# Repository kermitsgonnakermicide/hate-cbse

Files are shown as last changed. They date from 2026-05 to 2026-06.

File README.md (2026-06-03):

# hate-cbse
A desk-sized CoreXY pen plotter with a custom RP2350 based motherboard!

# why? 
### just why?
- i come from the great country of India, and as a result of that I'm in CBSE [(Central Board of Secondary Education)](https://www.cbse.gov.in/)
- CBSE, being a central board(for the entire country) and in general being decades behind other boards/methods has some quirky little requirements which seem utterly useless to the average individual
- one of those requirements is to a 'practical file' for maths, physics, chemistry and biology - these files are supposed to detail every single experiment you do in the lab and their results
- while this has great intentions, it has become so bad that a 'lab manual' has been published and students are expected to copy it word for word(not even kidding there) including the results and submit it
- i went through this myself and now that i'm moving into 11th(junior year) and the volume of experiments shoots straight up, I need a solution to this horrid problem

for additional context, please view this [youtube video](https://www.youtube.com/watch?v=U_G3jSLx4hc)
## enter, the hatecbse plotter
- this is an awesome corexy plotter that has about 300x300 mm of usable space, good enough for all my sheets and stuff
- its frame is built with 20x20 aluminium extrusion and is powered by NEMA17 stepper motors 
- while I initially thought I would skip on making a full on PCB for this project, you only hackclub once so I decided to make my own, printer motherboard-esque concotion around an RP2350B and the TMC2209 steppers(sticking with the breakout boards for that one purely because of cost)
- firmware wise, i'm not smart enough to write CNC plotter firmware so I'm using grblHAL, an opensource piece of firmware for all kinds of CNC plotters - you can check out Firmware/ for my config and and firmware file

# setup guide
- print and assemble the PCB(personally, i'm skipping all THT components for JLC assembly including a couple caps and resistors because I have them at home and they're for imp stuff(would appreciate being able to swap them out))
- print all files in production/Prints (quantity is indicated in the filename)
- assemble the frame(you will need a lot of T nuts for the alumnium extrusions)
- mount the PCB backplate, the motor holders + motor, belt guide
- assemble the toolhead and its profile, along with its linear actuator
- route your timing belts through center, motor pulley and ends
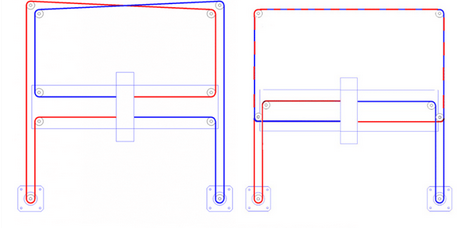
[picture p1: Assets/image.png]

> use this image for reference!
- put PCB on backplate, wire servos, steppers and limit switches to the board and anything else you want to add(I exposed a lot of power and I2C pins)
- give it USB power and 12v 5A power from your favourite power source(personally using my benchtop powersupply, but you could use anything)
- flash firmware and get to plotting!

# note for reviewer(s)
this project will be partially self funded out of sheer necessity, so please do not be concerned about any excess BOM cost

# Images
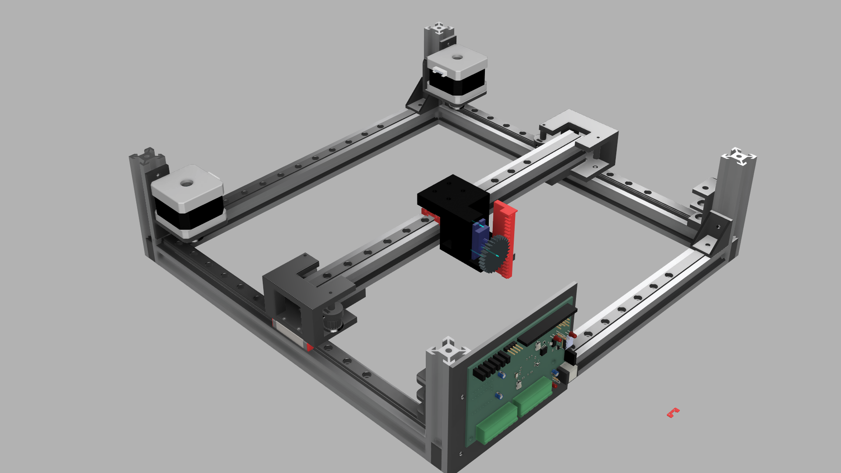
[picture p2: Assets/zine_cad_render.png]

> full render

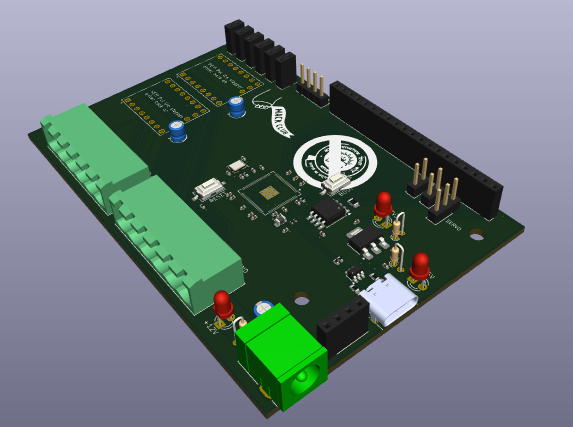
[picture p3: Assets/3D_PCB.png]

>PCB render

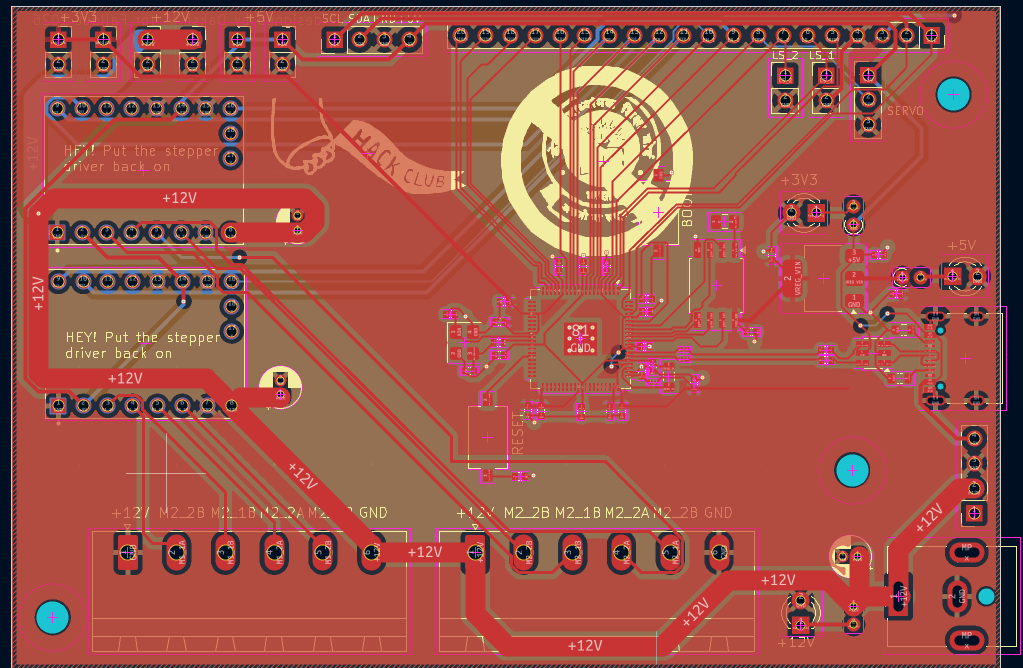
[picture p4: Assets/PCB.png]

> routed PCB

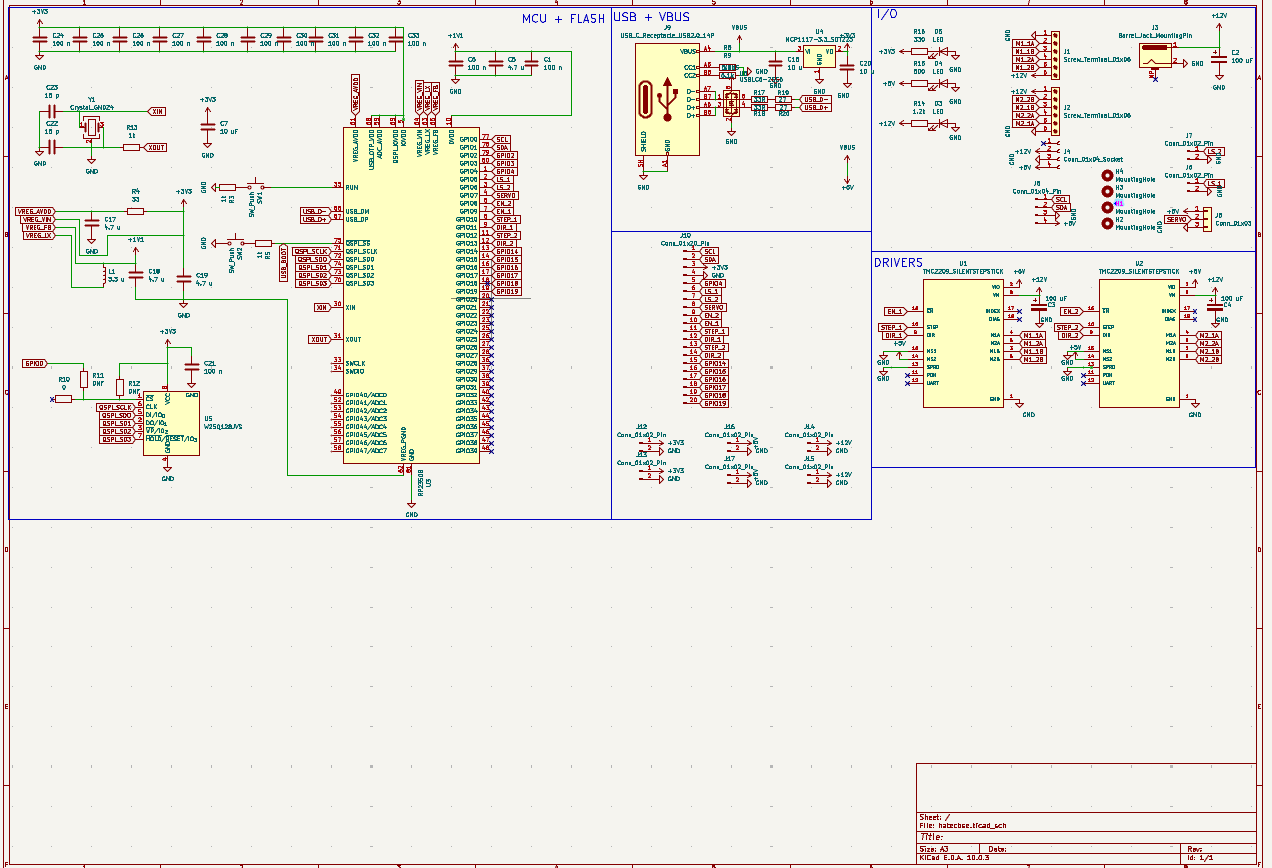
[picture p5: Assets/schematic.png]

> cleaned up schematic

# Zine
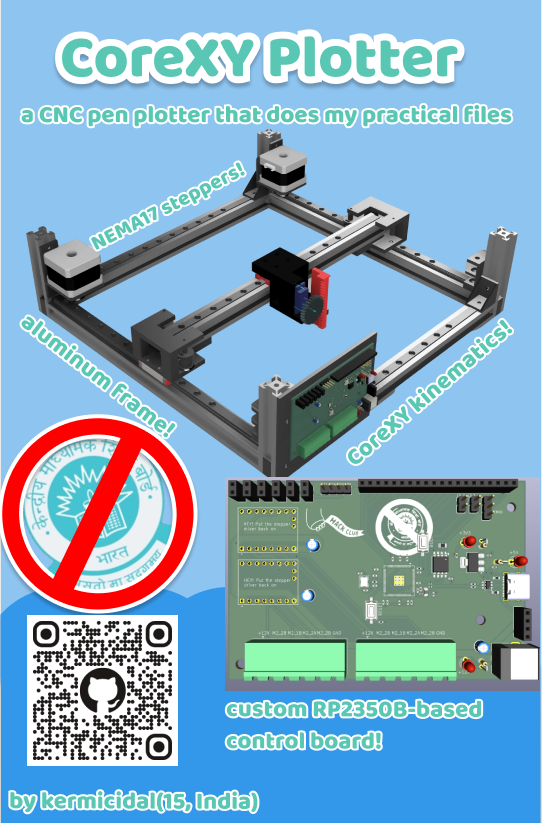
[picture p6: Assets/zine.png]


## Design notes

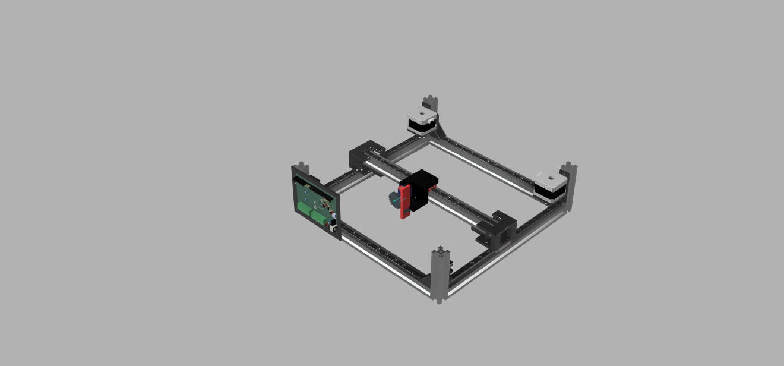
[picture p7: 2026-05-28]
Assets/render_cad.png

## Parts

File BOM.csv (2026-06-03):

Name | Link | Unit Price | Quantity | Total | Running | Notes
MGN9H LInear Rails | https://novo3d.in/mgn9h-linear-rail/?attribute_length=30cm | 10.43 | 3 | 31.29 | 31.29
MGN9H Blocks | https://novo3d.in/linear-guide-rail/?attribute_type=MGN9H | 5.73 | 3 | 17.19 | 48.48
Aluminium 3 way connector | https://novo3d.in/3-way-corner-connector/?attribute_type=2020 | 1.03 | 3 | 3.09 | 51.57
GT2 Timing belt | https://novo3d.in/gt2-timing-belt/ | 0.65 | 1 | 0.65 | 52.22 | Unit Price - 1 meter
2020 Aluminium Profile | https://novo3d.in/aluminium-profiles-2020/ | 6.2 | 1.86 | 11.532 | 63.752 | Unit Price - 1 meter
NEMA 17 | https://novo3d.in/42-stepper-motor/ | 6.05 | 2 | 12.1 | 75.852
TMC2209 | https://novo3d.in/mks-tmc2209/ | 4.54 | 2 | 9.08 | 84.932
MG90 servo | N/A | 0 | 0 | 0 | 84.932 | Already have
GT2 pulley | https://novo3d.in/gt2-pulley-16t-5mm-bore/ | 0.62 | 10 | 6.2 | 91.132
Filament |  | 0 | 0 | 0 | 91.132 | Already have
T nuts | https://novo3d.in/spring-t-nut/?attribute_size=M5 | 0.094 | 20 | 1.88 | 93.012
M5 Bolts | https://robokits.co.in/robot-parts/nut-bolts-standoffs/allen-cap-socket-head-bolts/m5-x-8mm-socket-head-cap-stainless-steel-304-bolt-moq-15pcs | 2.19 | 1 | 2.19 | 95.202 | pack of 15
PCB | please view seperate PCB bom for details |  |  | 92 | 187.202
TOTAL |  |  |  |  | 187.202

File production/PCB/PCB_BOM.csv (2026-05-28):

JLCPCB BOM Tool - BOM Matching
BOM name：bom-JLCPCB Assembly Order.xlsx |  |  | Download Time：2026-05-28 21:02:38 |  |  | * Our matching results are updated in real-time, but stock and prices may change. If it's been over 24 hours, please re-match before placing your order.
PCB Assembled Qty：5 |  |  | Est. Total Price：19.6919
Your BOM |  |  |  |  |  |  |  |  |  |  | Order Information
Top Designator | Bottom Designator | Comment | Footprint | JLCPCB Part # | Part # | Manufacturer | Footprint | Description | Category | Warning | JLCPCB Part # | Product link | Lib Type | Qty | Source | Total Price ($)
C1,C21,C24,C25,C26,C27,C28,C29,C30,C31,C32,C33,C6 |  | 100n | 402 |  | CC0402KRX7R7BB104 | YAGEO | 0402 | 100nF 16V X7R ±10% 0402 Multilayer Ceramic Capacitors MLCC - SMD/SMT ROHS | Multilayer Ceramic Capacitors MLCC - SMD/SMT | 1.The comment (CC0402KRX7R7BB104) of this part does not match the one (100n) provided in your BOM. Please confirm; | C60474 | https://jlcpcb.com/partdetail/YAGEO-CC0402KRX7R7BB104/C60474 | Extended | 38 | 38 JLCPCB | 0.0494
C7 |  | 10uF | 402 |  | CL05A106MQ5NUNC | Samsung Electro-Mechanics | 0402 | 10uF 6.3V X5R ±20% 0402 Multilayer Ceramic Capacitors MLCC - SMD/SMT ROHS | Multilayer Ceramic Capacitors MLCC - SMD/SMT | 1.Multiple lines in the BOM have been matched to the same part. Please check if the matching is correct. ; | C15525 | https://jlcpcb.com/partdetail/16204-CL05A106MQ5NUNC/C15525 | Basic | 20 | 20 JLCPCB | 0.192
C16,C20 |  | 10u | 402
C17,C18,C19,C5 |  | 4.7u | 402 |  | CL05A475MP5NRNC | Samsung Electro-Mechanics | 0402 | 10V 4.7uF X5R ±20% 0402 Multilayer Ceramic Capacitors MLCC - SMD/SMT ROHS | Multilayer Ceramic Capacitors MLCC - SMD/SMT | 1.The comment (CL05A475MP5NRNC) of this part does not match the one (4.7u) provided in your BOM. Please confirm; | C23733 | https://jlcpcb.com/partdetail/24469-CL05A475MP5NRNC/C23733 | Basic | 20 | 20 JLCPCB | 0.128
C22,C23 |  | 15p | 402 |  | 0402CG150J500NT | FH (Guangdong Fenghua Advanced Tech) | 0402 | 15pF 50V C0G ±5% 0402 Multilayer Ceramic Capacitors MLCC - SMD/SMT ROHS | Multilayer Ceramic Capacitors MLCC - SMD/SMT | 1.The comment (0402CG150J500NT) of this part does not match the one (15p) provided in your BOM. Please confirm; | C1548 | https://jlcpcb.com/partdetail/1900-0402CG150J500NT/C1548 | Basic | 20 | 20 JLCPCB | 0.028
J3 |  | Barrel_Jack_MountingPin | BarrelJack_CUI_PJ-063AH_Horizontal |  | PJ-063AH | CUI | 插件 | -25℃~+85℃ 24V 2mm 6.5mm 8A DC Power Jack Right Angle 插件 DC Power Connectors ROHS | DC Power Connectors |  | C22434582 | https://jlcpcb.com/partdetail/CUI-PJ063AH/C22434582 | Extended | 2 | 2 JLCPCB | 5.0904
J9 |  | USB_C_Receptacle_USB2.0_14P | USB_C_Receptacle_XKB_U262-16XN-4BVC11 |  | TYPE-C-31-M-12 | Korean Hroparts Elec | SMD | -30℃~+80℃ 1 10,000 cycles 16P 20V 5A 7.35mm Female Surface Mount, Right Angle Type-C SMD USB Connectors ROHS | USB Connectors |  | C165948 | https://jlcpcb.com/partdetail/Korean_HropartsElec-TYPE_C_31_M12/C165948 | Extended | 2 | 2 JLCPCB | 0.371
L1 |  | 3.3u | 805 |  | AOTA-B201610S3R3-101-T | Abracon LLC | 0806 | 0806 Power Inductors ROHS | Power Inductors |  | C42411119 | https://jlcpcb.com/partdetail/AbraconLLC-AOTA_B201610S3R3_101T/C42411119 | Extended | 5 | 5 JLCPCB | 1.407
R4 |  | RC0402JR-0733RL | 201 |  | RC0402JR-0733RL | YAGEO | 0402 | -55℃~+155℃ 33Ω 50V 62.5mW Thick Film Resistor ±100ppm/℃ ±5% 0402 Chip Resistor - Surface Mount ROHS | Chip Resistor - Surface Mount |  | C137880 | https://jlcpcb.com/partdetail/YAGEO-RC0402JR0733RL/C137880 | Extended | 20 | 20 JLCPCB | 0.016
R8,R9 |  | 5.1k | 603 |  | 0603WAF270JT5E | UNI-ROYAL(Uniroyal Elec) | 0603 | -55℃~+155℃ 100mW 27Ω 75V Thick Film Resistor ±1% ±200ppm/℃ 0603 Chip Resistor - Surface Mount ROHS | Chip Resistor - Surface Mount | 1.The comment (0603WAF270JT5E) of this part does not match the one (5.1k) provided in your BOM. Please confirm; | C25190 | https://jlcpcb.com/partdetail/25933-0603WAF270JT5E/C25190 | Extended | 20 | 20 JLCPCB | 0.03
R10 |  | 0 | 805 |  | 0805W8F0000T5E | UNI-ROYAL(Uniroyal Elec) | 0805 | -55℃~+155℃ 0Ω 125mW 150V Thick Film Resistor ±1% ±800ppm/℃ 0805 Chip Resistor - Surface Mount ROHS | Chip Resistor - Surface Mount | 1.The comment (0805W8F0000T5E) of this part does not match the one (0) provided in your BOM. Please confirm; | C17477 | https://jlcpcb.com/partdetail/18165-0805W8F0000T5E/C17477 | Basic | 20 | 20 JLCPCB | 0.044
R13,R3,R5 |  | 1k | 402 |  | 0402WGF1001TCE | UNI-ROYAL(Uniroyal Elec) | 0402 | -55℃~+155℃ 1kΩ 50V 62.5mW Thick Film Resistor ±1% ±100ppm/℃ 0402 Chip Resistor - Surface Mount ROHS | Chip Resistor - Surface Mount |  | C11702 | https://jlcpcb.com/partdetail/12256-0402WGF1001TCE/C11702 | Basic | 20 | 20 JLCPCB | 0.02
R17,R18 |  | 33R | 402 |  | 0402WGF330JTCE | UNI-ROYAL(Uniroyal Elec) | 0402 | -55℃~+155℃ 33Ω 50V 62.5mW Thick Film Resistor ±1% ±100ppm/℃ 0402 Chip Resistor - Surface Mount ROHS | Chip Resistor - Surface Mount |  | C25105 | https://jlcpcb.com/partdetail/25848-0402WGF330JTCE/C25105 | Basic | 20 | 20 JLCPCB | 0.014
R19,R20 |  | 27 | 201 |  | 0201WMJ0270TEE | UNI-ROYAL(Uniroyal Elec) | 0201 | -55℃~+155℃ 25V 27Ω 50mW Thick Film Resistor ±200ppm/℃ ±5% 0201 Chip Resistor - Surface Mount ROHS | Chip Resistor - Surface Mount | 1.The comment (0201WMJ0270TEE) of this part does not match the one (27) provided in your BOM. Please confirm; | C270320 | https://jlcpcb.com/partdetail/259850-0201WMJ0270TEE/C270320 | Extended | 20 | 20 JLCPCB | 0.014
SW1,SW2 |  | SW_Push | SW_Tactile_SPST_NO_Straight_CK_PTS636Sx25SMTRLFS |  | PTS636SK25SMTRLFS | C&K | SMD,6x3.5mm | -40℃~+90℃ 12V 2.5N 3.7mm 50mA 6.1mm Gull Wing IP40 No Rectangular Button SPST-NO Surface Mount,Vertical SMD,6x3.5mm Tactile Switches ROHS | Tactile Switches |  | C2689642 | https://jlcpcb.com/partdetail/CK-PTS636SK25SMTRLFS/C2689642 | Extended | 5 | 5 JLCPCB | 1.7515
U3 |  | RP2350B | QFN-80-1EP_10x10mm_P0.4mm_EP3.4x3.4mm |  | RP2350B | Raspberry Pi | QFN-80-EP | Power-on reset (POR)、Watchdog reset、External pin reset (NRST)、Built-in general-purpose timer、Integrated LDO、True random number generator (TRNG)、Hardware ECC check、Independent watchdog (IWDG) QFN-80-EP Microcontrollers (MCU/MPU/SOC) ROHS | Microcontrollers (MCU/MPU/SOC) |  | C42415655 | https://jlcpcb.com/partdetail/RaspberryPi-RP2350B/C42415655 | Extended | 2 | 2 JLCPCB | 2.505
U4 |  | NCP1117-3.3_SOT223 | SOT-223-3_TabPin2 |  | NCP1117STAT3G | onsemi | SOT-223 | 0.003%Vout 0℃~+125℃@(Ta) 1 1.25V~18.8V 1.2V@(800mA) 1A 20V 6mA 73dB@(120Hz) Adjustable Over Current Protection、Over Temperature Protection Positive SOT-223 Voltage Regulators - Linear, Low Drop Out (LDO) Regulators ROHS | Voltage Regulators - Linear, Low Drop Out (LDO) Regulators |  | C20546 | https://jlcpcb.com/partdetail/onsemi-NCP1117STAT3G/C20546 | Extended | 5 | 5 JLCPCB | 1.4755
U5 |  | W25Q128JVS | SOIC-8_5.3x5.3mm_P1.27mm |  | W25Q128JVSIQ | Winbond Elec | SOIC-8-208mil | -40℃~+85℃ 100,000 cycles 120ms@(32KB) 128Mbit 133MHz 1uA 2.7V~3.6V 20 Years 3ms SPI SOIC-8-208mil NOR FLASH ROHS | NOR FLASH | 1.The comment (W25Q128JVSIQ) of this part does not match the one (W25Q128JVS) provided in your BOM. Please confirm; | C97521 | https://jlcpcb.com/partdetail/WinbondElec-W25Q128JVSIQ/C97521 | Basic | 2 | 2 JLCPCB | 4.6236
U6 |  | USBLC6-2SC6 | SOT-23-6 |  | USBLC6-2SC6-ES | ElecSuper | SOT-23-6L | -40℃~+85℃ 0.6pF 15V 1uA 2 4.5A 5V 6V 70W@8/20us ESD IEC 61000-4-2 Unidirectional SOT-23-6L ESD and Surge Protection (TVS/ESD) ROHS | ESD And Surge Protection (TVS/ESD) |  | C5180249 | https://jlcpcb.com/partdetail/ElecSuper-USBLC6_2SC6ES/C5180249 | Extended | 10 | 10 JLCPCB | 0.276
Y1 |  | Crystal_GND24 | Crystal_SMD_Abracon_ABM8G-4Pin_3.2x2.5mm |  | ABM8-272-T3 | Abracon LLC | SMD3225-4P | -40℃~+85℃ 10pF 12MHz 50Ω Crystal Oscillator ±30ppm ±30ppm SMD3225-4P Crystals ROHS | Crystals |  | C20625731 | https://jlcpcb.com/partdetail/AbraconLLC-ABM8_272T3/C20625731 | Extended | 5 | 5 JLCPCB | 1.4645
C2,C3,C4 |  | 100uF | CP_Radial_D4.0mm_P1.50mm |  | 100uF | PANASONIC | CAP-SMD | CAP-SMD New Arrivals ROHS |  |  | C20618601 | https://jlcpcb.com/partdetail/PANASONIC-100uF/C20618601 | Extended | 6 | 0 JLCPCB | 0
R15 |  | 500 | R_Axial_DIN0204_L3.6mm_D1.6mm_P1.90mm_Vertical |  | 500 | Keystone | - | - ROHS | BatteryConnector |  | C238121 | https://jlcpcb.com/partdetail/Keystone-500/C238121 | Extended | 2 | 0 JLCPCB | 0
R16 |  | 330 | R_Axial_DIN0204_L3.6mm_D1.6mm_P1.90mm_Vertical |  | 330 | JKL Components | - | 14V 80mA - LED Indication - Discrete ROHS | LED Indication - Discrete |  | C22190030 | https://jlcpcb.com/partdetail/JKLComponents-330/C22190030 | Extended | 2 | 0 JLCPCB | 0
U1,U2 |  | TMC2209_SILENTSTEPSTICK | MODULE_TMC2209_SILENTSTEPSTICK |  | TMC2209SILENTSTEPSTICK | TRINAMIC Motion Control GmbH | - | Power Management - Modules ROHS | Modules | 1.The comment (TMC2209SILENTSTEPSTICK) of this part does not match the one (TMC2209_SILENTSTEPSTICK) provided in your BOM. Please confirm; | C17375345 | https://jlcpcb.com/partdetail/18504516-TMC2209SILENTSTEPSTICK/C17375345 | Extended | 4 | 0 JLCPCB | 0
D3,D4,D5 |  | LED | LED_D3.0mm |  | No Part Selected
J1,J2 |  | Screw_Terminal_01x06 | PhoenixContact_MSTBA_2,5_6-G_1x06_P5.00mm_Horizontal |  | No Part Selected
J4 |  | Conn_01x04_Socket | PinSocket_1x04_P2.54mm_Vertical |  | No Part Selected
J5 |  | Conn_01x03 | PinHeader_1x03_P2.54mm_Vertical |  | No Part Selected
J6,J7 |  | Conn_01x02_Pin | PinHeader_1x02_P2.54mm_Vertical |  | No Part Selected
J8 |  | Conn_01x04_Pin | PinHeader_1x04_P2.54mm_Vertical |  | No Part Selected
J10 |  | Conn_01x20_Pin | PinSocket_1x20_P2.54mm_Vertical |  | No Part Selected
J12,J13,J14,J15,J16,J17 |  | Conn_01x02_Pin | PinSocket_1x02_P2.54mm_Vertical |  | No Part Selected
R14 |  | 1.2k | R_Axial_DIN0204_L3.6mm_D1.6mm_P1.90mm_Vertical |  | No Part Selected

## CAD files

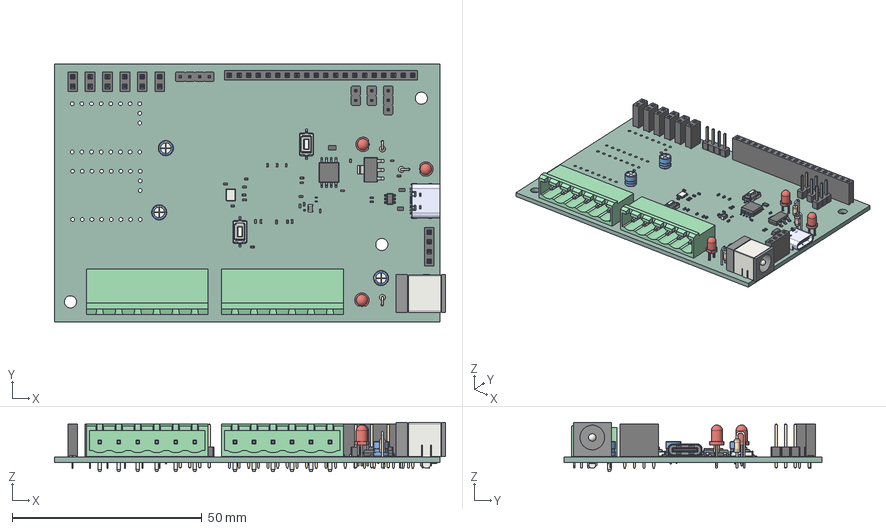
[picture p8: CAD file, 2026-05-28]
CAD/pcb.step
102.9 x 68.0 x 13.0 mm
LED_D3.0mm x 3
C_0402_1005Metric x 22
SOIC-8_5.3x5.3mm_P1.27mm
PinSocket_1x02_P2.54mm_Vertical x 6
CP_Radial_D40mm_P150mm x 3
R_0201_0603Metric x 3
R_Axial_DIN0204_L36mm_D16mm_P190mm_Vertical x 3
BarrelJack_CUI_PJ-063AH_Horizontal
PTS636Sx25SMTRLFS x 2
R_0402_1005Metric x 5
L_0805_2012Metric
PinSocket_1x20_P2.54mm_Vertical
SOT-223
SOT-23-6
Crystal_SMD_Abracon_ABM8G-4Pin_3.2x2.5mm
MSTBA_01x06_G_5_00mm x 2
TYPE-C-31-M-12
PinHeader_1x02_P254mm_Vertical x 2
R_0805_2012Metric
PinSocket_1x04_P2.54mm_Vertical
PinHeader_1x03_P254mm_Vertical
R_0603_1608Metric x 2
PinHeader_1x04_P254mm_Vertical
hatecbse_PCB

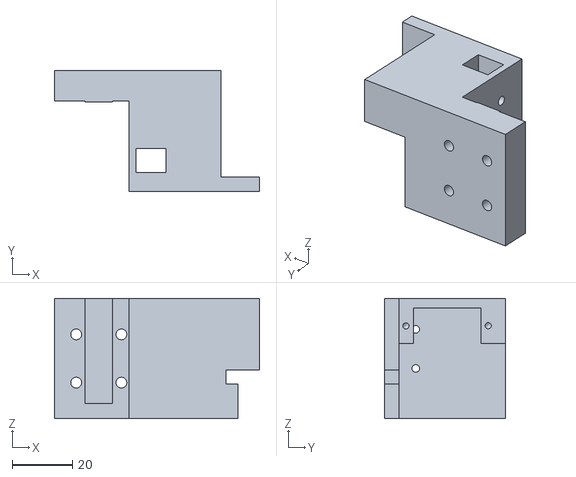
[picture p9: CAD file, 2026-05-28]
production/Prints/toolhead_1x.stl
68.0 x 40.0 x 39.9

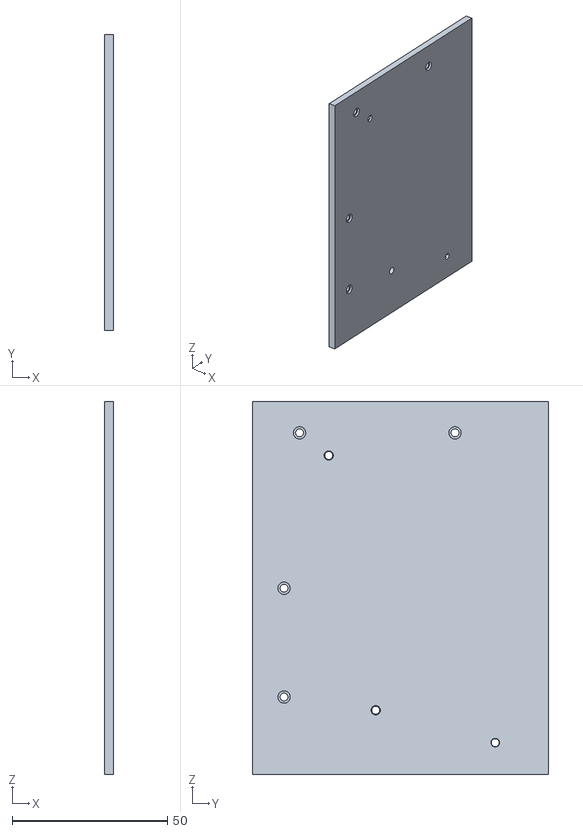
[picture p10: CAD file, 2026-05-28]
production/Prints/PCB_plate_1x.stl
3.00 x 95.1 x 120.0

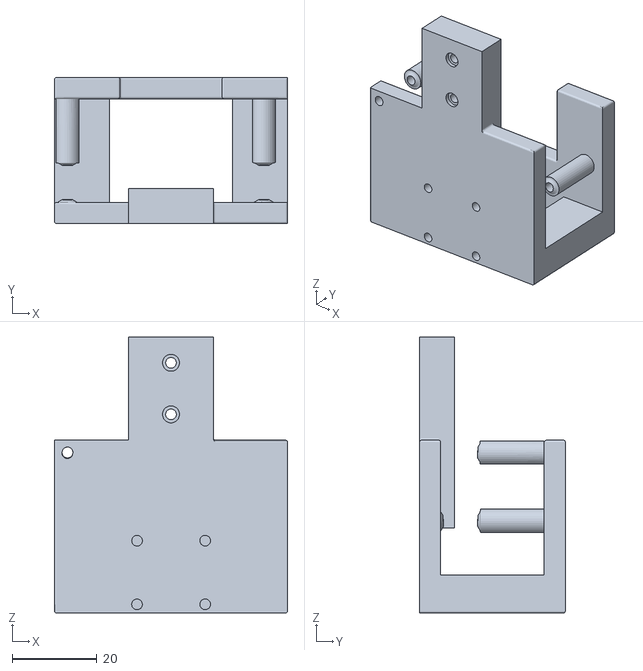
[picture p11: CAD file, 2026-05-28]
production/Prints/y_thing_2x.stl
54.9 x 34.4 x 65.0

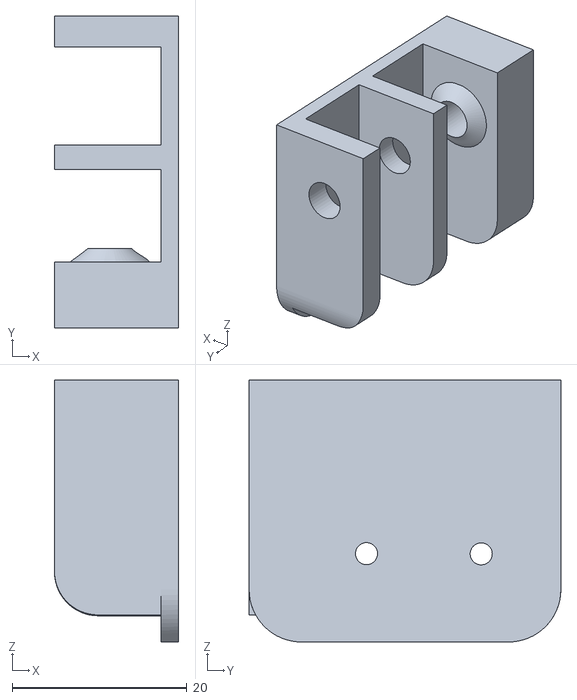
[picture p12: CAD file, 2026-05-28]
production/Prints/belt_holder_2x.stl
14.2 x 35.7 x 30.0

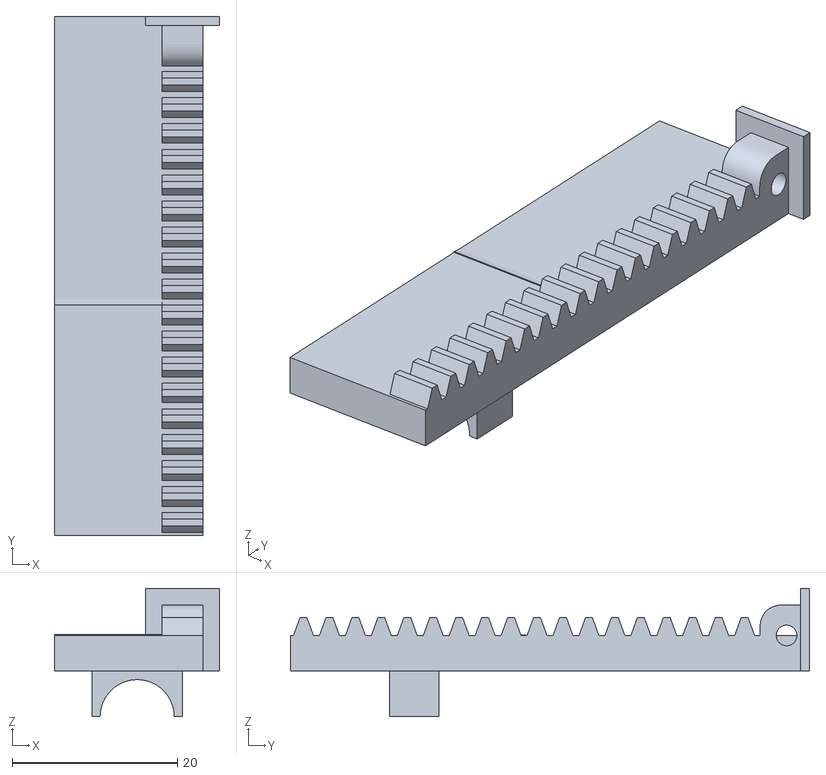
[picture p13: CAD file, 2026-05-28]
production/Prints/linear_actuator_rail_1x.stl
20.0 x 62.8 x 15.5

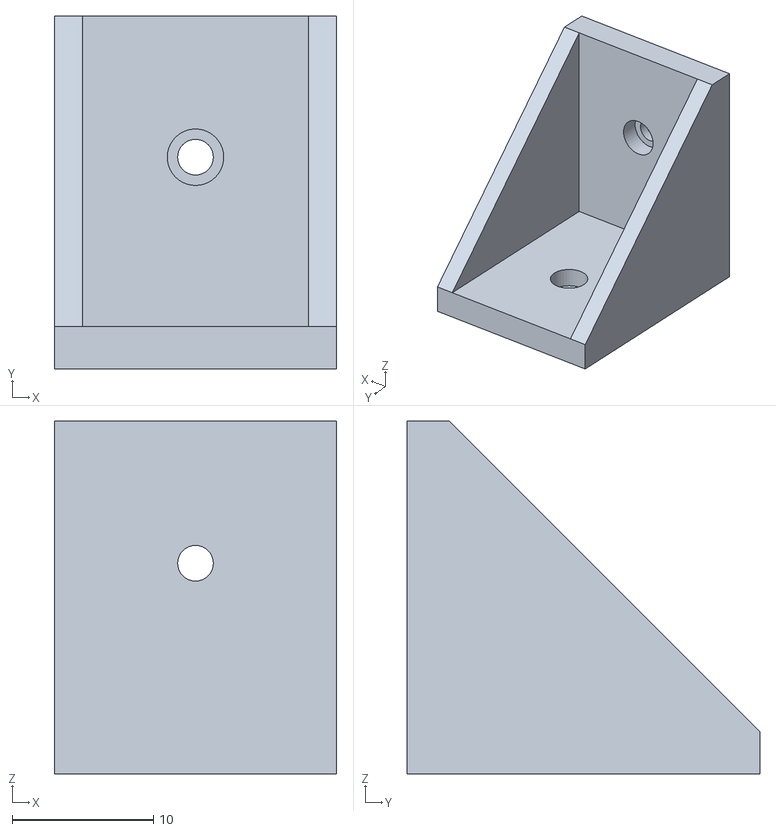
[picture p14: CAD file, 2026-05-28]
production/Prints/corner_bracket_4x.stl
20.0 x 25.0 x 25.0

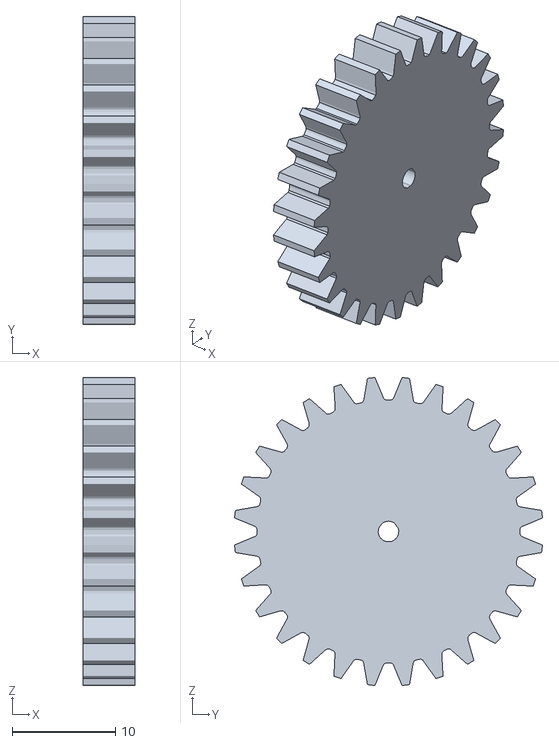
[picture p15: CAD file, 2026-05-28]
production/Prints/linear_actuator_gear_1x.stl
5.00 x 29.9 x 29.9

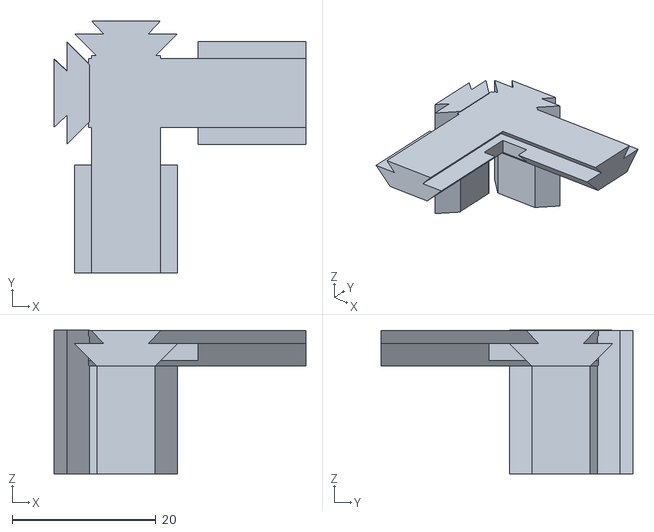
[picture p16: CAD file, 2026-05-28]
production/Prints/3_way_bracket_4x.stl
35.0 x 35.0 x 20.0

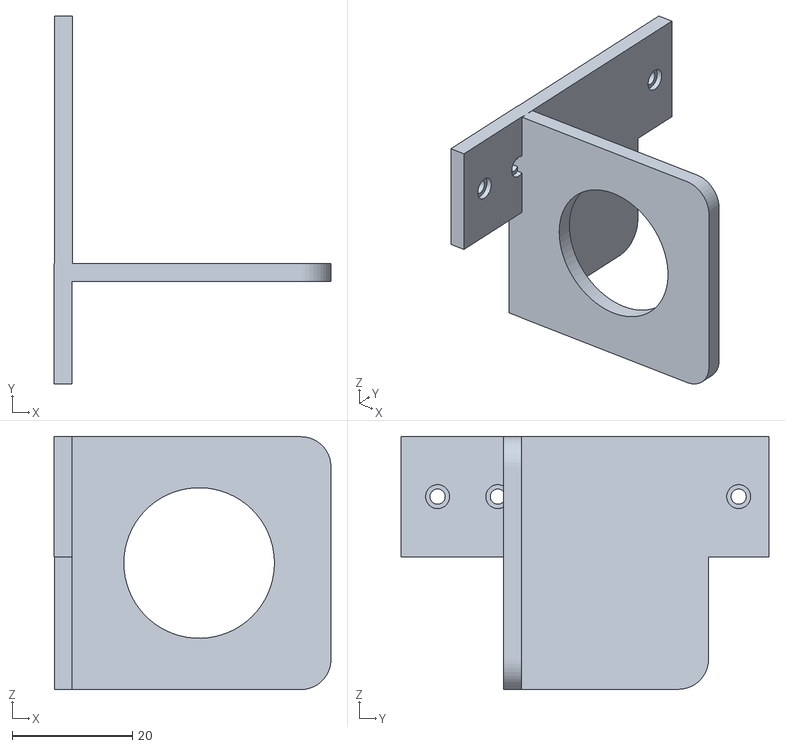
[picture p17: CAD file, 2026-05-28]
production/Prints/motor_holder_2x.stl
46.0 x 61.0 x 42.0

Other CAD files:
hatecbse.step

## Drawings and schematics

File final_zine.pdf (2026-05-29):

# CoreXY Plotter

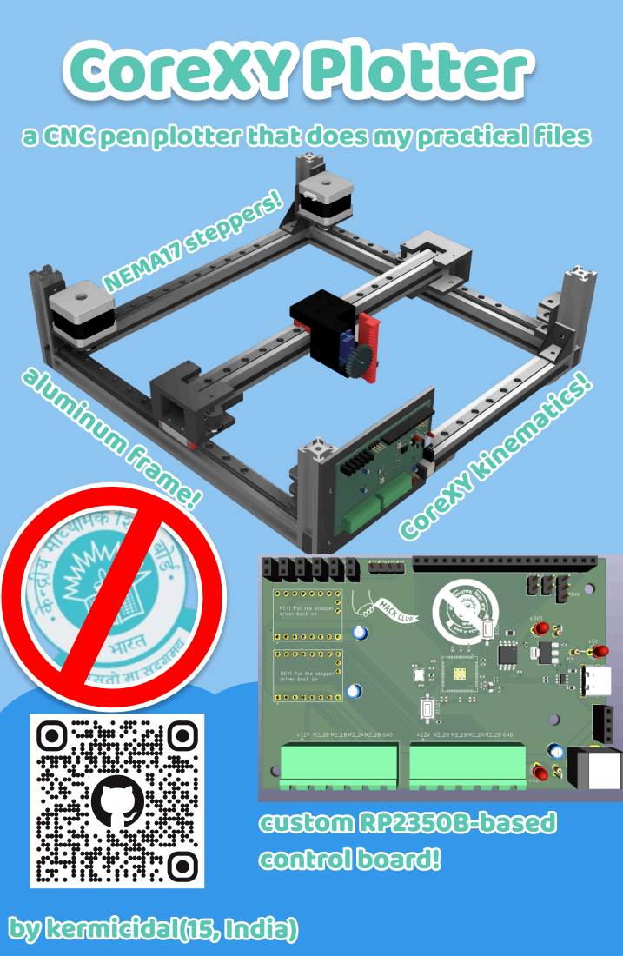
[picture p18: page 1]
NEMA17 steppers!; aluminum frame!; CoreXY kinematics!; custom RP2350B-based; control board!

a CNC pen plotter that does my practical files

by kermicidal(15, India)

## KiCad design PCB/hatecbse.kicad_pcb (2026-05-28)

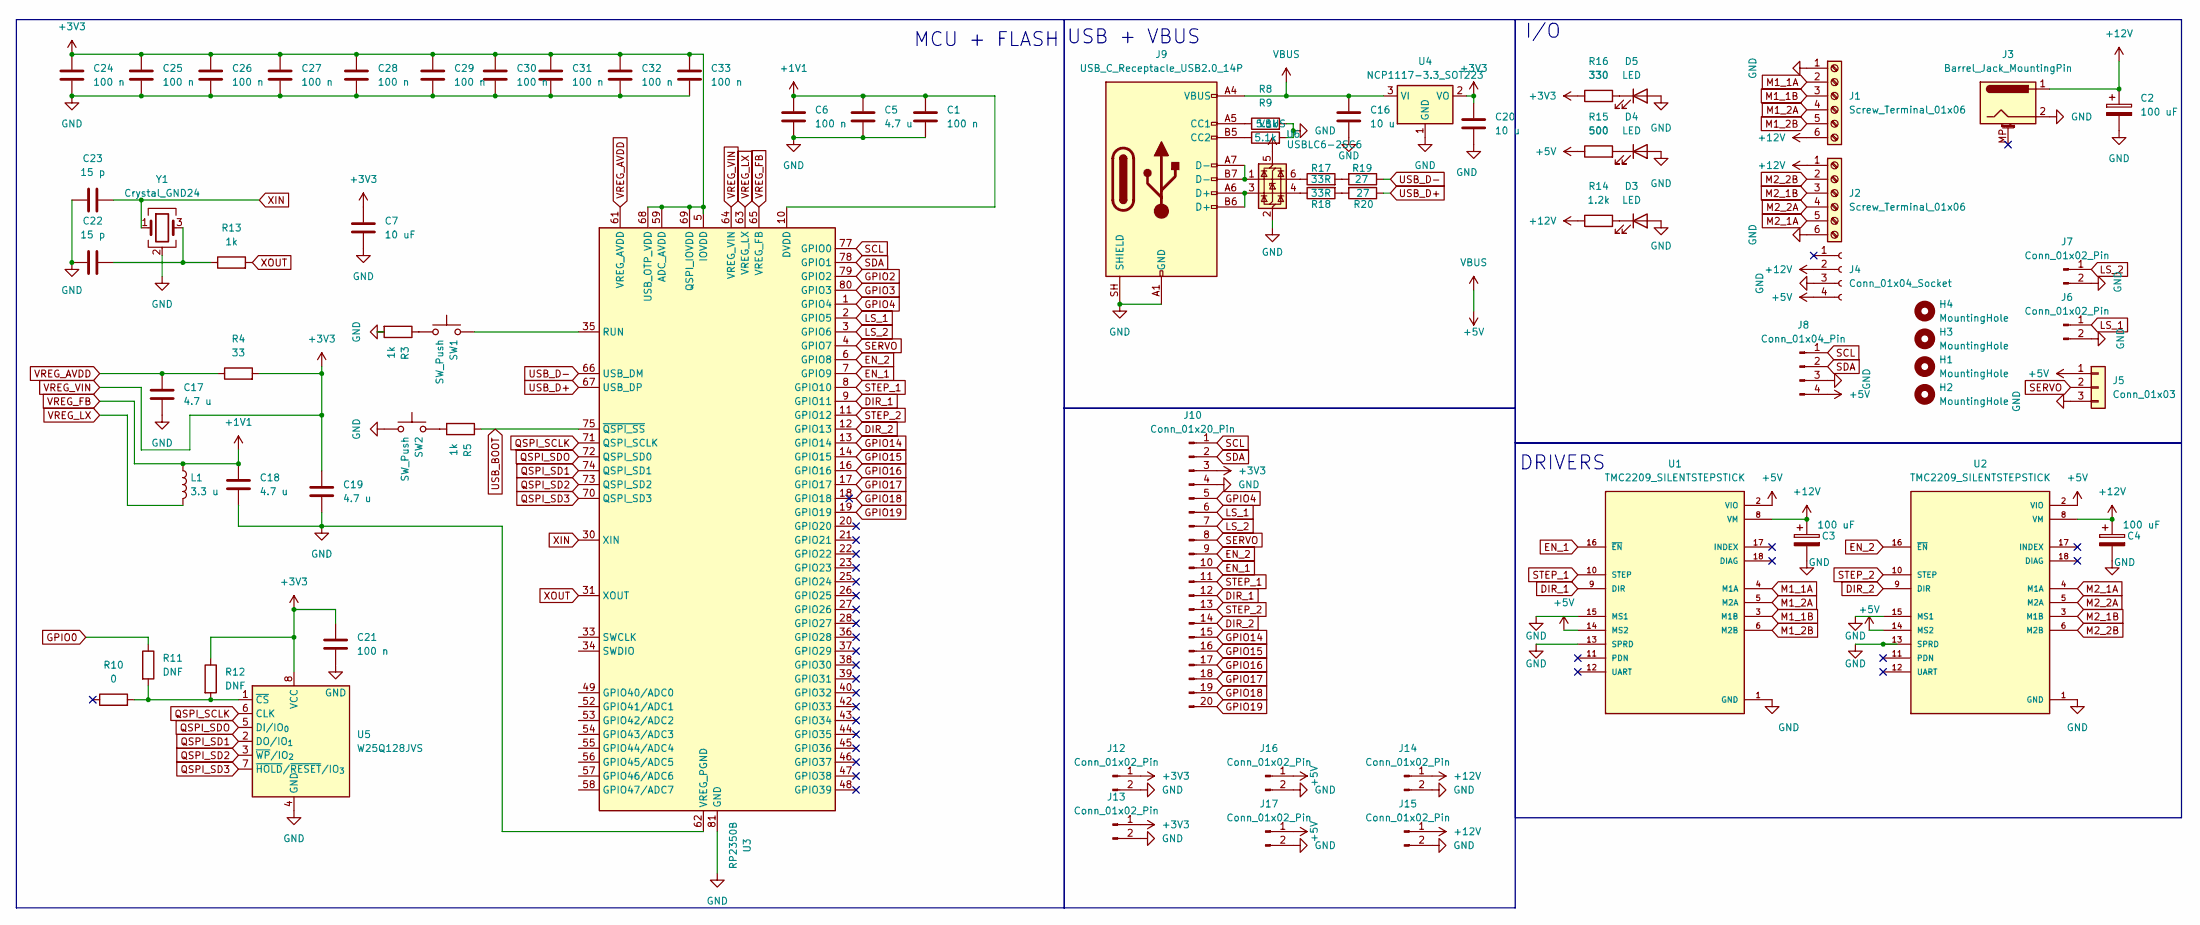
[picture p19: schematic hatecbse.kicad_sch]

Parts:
C1, C6, C21, C24, C25, C26, C27, C28, C29, C30, C31, C32, C33: 100 n; C_0402_1005Metric
C2, C3, C4: 100 uF; CP_Radial_D4.0mm_P1.50mm
C5, C17, C18, C19: 4.7 u; C_0402_1005Metric
C7: 10 uF; C_0402_1005Metric
C16, C20: 10 u; C_0402_1005Metric
C22, C23: 15 p; C_0402_1005Metric
D3, D4, D5: LED; LED_D3.0mm
H1, H2, H3, H4: MountingHole; MountingHole_3.2mm_M3
J1, J2: Screw_Terminal_01x06; PhoenixContact_MSTBA_2,5_6-G_1x06_P5.00mm_Horizontal
J3: Barrel_Jack_MountingPin; BarrelJack_CUI_PJ-063AH_Horizontal
J4: Conn_01x04_Socket; PinSocket_1x04_P2.54mm_Vertical
J5: Conn_01x03; PinHeader_1x03_P2.54mm_Vertical
J6, J7: Conn_01x02_Pin; PinHeader_1x02_P2.54mm_Vertical
J8: Conn_01x04_Pin; PinHeader_1x04_P2.54mm_Vertical
J9: USB_C_Receptacle_USB2.0_14P; USB_C_Receptacle_XKB_U262-16XN-4BVC11
J10: Conn_01x20_Pin; PinSocket_1x20_P2.54mm_Vertical
J12, J13, J14, J15, J16, J17: Conn_01x02_Pin; PinSocket_1x02_P2.54mm_Vertical
L1: 3.3 u; L_0805_2012Metric
R3, R5, R13: 1k; R_0402_1005Metric
R4: 33; R_0201_0603Metric
R8, R9: 5.1k; R_0603_1608Metric
R10: 0; R_0805_2012Metric
R11, R12: DNF
R14: 1.2k; R_Axial_DIN0204_L3.6mm_D1.6mm_P1.90mm_Vertical
R15: 500; R_Axial_DIN0204_L3.6mm_D1.6mm_P1.90mm_Vertical
R16: 330; R_Axial_DIN0204_L3.6mm_D1.6mm_P1.90mm_Vertical
R17, R18: 33R; R_0402_1005Metric; LCSC C25105
R19, R20: 27; R_0201_0603Metric
SW1, SW2: SW_Push; SW_Tactile_SPST_NO_Straight_CK_PTS636Sx25SMTRLFS
U1, U2: TMC2209_SILENTSTEPSTICK; MODULE_TMC2209_SILENTSTEPSTICK; PARTREV 1.20
U3: RP2350B; QFN-80-1EP_10x10mm_P0.4mm_EP3.4x3.4mm
U4: NCP1117-3.3_SOT223; SOT-223-3_TabPin2
U5: W25Q128JVS; SOIC-8_5.3x5.3mm_P1.27mm
U6: USBLC6-2SC6; SOT-23-6; LCSC C5180249
Y1: Crystal_GND24; Crystal_SMD_Abracon_ABM8G-4Pin_3.2x2.5mm

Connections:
+5V: C16.1, J4.4, J5.1, J8.4, J9.A4 (VBUS), J9.A9 (VBUS), J9.B4 (VBUS), J9.B9 (VBUS), J16.1, J17.1, R15.1, U1.2 (VIO), U1.14 (MS2), U2.2 (VIO), U2.14 (MS2), U4.3 (VI), U6.5 (VBUS)
+12V: C2.1, C3.1, C4.1, J1.6, J2.1, J3.1, J4.2, J14.1, J15.1, R14.1, U1.8 (VM), U2.8 (VM)
DIR_1: J10.12, U1.9 (DIR), U3.9 (GPIO11)
DIR_2: J10.14, U2.9 (DIR), U3.12 (GPIO13)
EN_1: J10.10, U1.16 (~EN), U3.7 (GPIO9)
EN_2: J10.9, U2.16 (~EN), U3.6 (GPIO8)
GND: C1.2, C2.2, C3.2, C4.2, C5.2, C6.2, C7.2, C16.2, C17.1, C18.2, C19.2, C20.2, C21.2, C22.1, C23.1, C24.2, C25.2, C26.2, C27.2, C28.2, C29.2, C30.2, C31.2, C32.2, C33.2, D3.2 (A), D4.2 (A), D5.2 (A), J1.1, J2.6, J3.2, J4.3, J5.3, J6.2, J7.2, J8.3, J9.A1 (GND), J9.A12 (GND), J9.B1 (GND), J9.B12 (GND), J9.SH (SHIELD), J10.4, J12.2, J13.2, J14.2, J15.2, J16.2, J17.2, R3.2, R8.2, R9.2, SW2.1, U1.1 (GND), U1.7 (GND), U1.13 (SPRD), U1.15 (MS1), U2.1 (GND), U2.7 (GND), U2.13 (SPRD), U2.15 (MS1), U3.62 (VREG_PGND), U3.81 (GND), U4.1 (GND), U5.4 (GND), U6.2 (GND), Y1.2 (G), Y1.4 (G)
GPIO2: U3.79 (GPIO2)
GPIO3: U3.80 (GPIO3)
GPIO4: J10.5, U3.1 (GPIO4)
GPIO14: J10.15, U3.13 (GPIO14)
GPIO15: J10.16, U3.14 (GPIO15)
GPIO16: J10.17, U3.16 (GPIO16)
GPIO17: J10.18, U3.17 (GPIO17)
GPIO18: J10.19, U3.18 (GPIO18)
GPIO19: J10.20, U3.19 (GPIO19)
LS_1: J6.1, J10.6, U3.2 (GPIO5)
LS_2: J7.1, J10.7, U3.3 (GPIO6)
M1_1A: J1.2, U1.4 (M1A)
M1_1B: J1.3, U1.3 (M1B)
M1_2A: J1.4, U1.5 (M2A)
M1_2B: J1.5, U1.6 (M2B)
M2_1A: J2.5, U2.4 (M1A)
M2_1B: J2.3, U2.3 (M1B)
M2_2A: J2.4, U2.5 (M2A)
M2_2B: J2.2, U2.6 (M2B)
unnamed: C22.2, R13.1, Y1.3
unnamed: D3.1 (K), R14.2
unnamed: D4.1 (K), R15.2
unnamed: D5.1 (K), R16.2
unnamed: J9.A5 (CC1), R8.1
unnamed: J9.B5 (CC2), R9.1
unnamed: J9.A6 (D+), J9.B6 (D+), U6.3 (I/O2)
unnamed: J9.A7 (D-), J9.B7 (D-), U6.1 (I/O1)
unnamed: R3.1, SW1.1
unnamed: R5.2, SW2.2
unnamed: R17.1, U6.6 (I/O1)
unnamed: R17.2, R19.2
unnamed: R18.1, U6.4 (I/O2)
unnamed: R18.2, R20.2
unnamed: SW1.2, U3.35 (RUN)
unnamed: R10.2, R11.2, R12.2, U5.1 (~CS)
QSPI_SCLK: U3.71 (QSPI_SCLK), U5.6 (CLK)
QSPI_SD1: U3.74 (QSPI_SD1), U5.2 (DO/IO_{1})
QSPI_SD2: U3.73 (QSPI_SD2), U5.3 (~WP/IO_{2})
QSPI_SD3: U3.70 (QSPI_SD3), U5.7 (~HOLD/~RESET/IO_{3})
QSPI_SDO: U3.72 (QSPI_SD0), U5.5 (DI/IO_{0})
SCL: J8.1, J10.1, U3.77 (GPIO0)
SDA: J8.2, J10.2, U3.78 (GPIO1)
SERVO: J5.2, J10.8, U3.4 (GPIO7)
STEP_1: J10.11, U1.10 (STEP), U3.8 (GPIO10)
STEP_2: J10.13, U2.10 (STEP), U3.11 (GPIO12)
USB_BOOT: R5.1, U3.75 (~QSPI_SS)
USB_D+: R20.1, U3.67 (USB_DP)
USB_D-: R19.1, U3.66 (USB_DM)
VREG_AVDD: C17.2, R4.1, U3.61 (VREG_AVDD)
VREG_FB: C1.1, C5.1, C6.1, C18.1, L1.1, U3.10 (DVDD), U3.32 (DVDD), U3.51 (DVDD), U3.65 (VREG_FB)
VREG_LX: L1.2, U3.63 (VREG_LX)
VREG_VIN: C7.1, C19.1, C20.1, C21.1, C24.1, C25.1, C26.1, C27.1, C28.1, C29.1, C30.1, C31.1, C32.1, C33.1, J10.3, J12.1, J13.1, R4.2, R12.1, R16.1, U3.5 (IOVDD), U3.15 (IOVDD), U3.24 (IOVDD), U3.29 (IOVDD), U3.41 (IOVDD), U3.50 (IOVDD), U3.59 (ADC_AVDD), U3.60 (IOVDD), U3.64 (VREG_VIN), U3.68 (USB_OTP_VDD), U3.69 (QSPI_IOVDD), U3.76 (IOVDD), U4.2 (VO), U5.8 (VCC)
XIN: C23.2, U3.30 (XIN), Y1.1
XOUT: R13.2, U3.31 (XOUT)

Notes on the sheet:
MCU + FLASH
DRIVERS
USB + VBUS
I/O

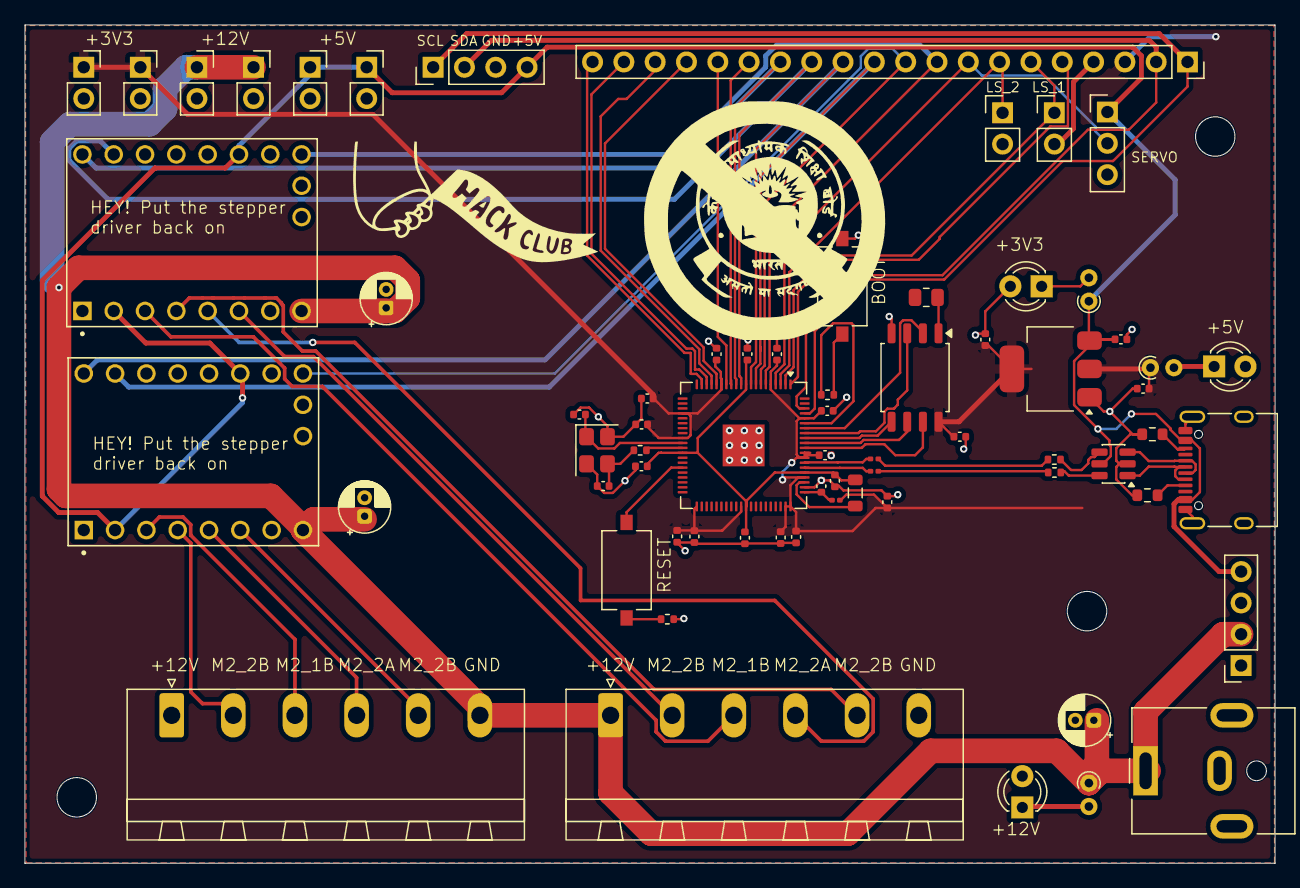
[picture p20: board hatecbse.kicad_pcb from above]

Board: 4 copper layers, 101.4 x 68.0 mm, 71 parts (0 on the bottom side), 59 nets.

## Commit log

2026-05-19 first one
    [hatecbse.kicad_pcb, hatecbse.kicad_sch]
2026-05-28 finally done with PCB
    [hatecbse.csv, hatecbse.kicad_pcb, hatecbse.step]
2026-05-28 update 3d files
    [3_way_bracket_4x.stl, PCB_plate_1x.stl, belt_holder_2x.stl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]
2026-05-28 updates and some stuff
    [3_way_bracket_4x.stl, BOM.csv, PCB_plate_1x.stl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]
2026-05-28 full updates for everything
    [hatecbse.kicad_pcb, hatecbse.kicad_sch]
2026-05-28 final hardware commit
    [3_way_bracket_4x.stl, PCB_plate_1x.stl, belt_holder_2x.stl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]
2026-05-29 add BOM
    [BOM.csv]
2026-06-03 add TOTAL row to BOM
    [BOM.csv]
